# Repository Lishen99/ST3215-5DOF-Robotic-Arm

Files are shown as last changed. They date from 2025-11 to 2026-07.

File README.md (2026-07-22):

# 5-DOF Robotic Arm Control System

Advanced control system for a 5-DOF robotic arm using ST3215 servo motors. This repository contains **multiple control implementations** ranging from direct Python control to high-performance embedded systems, providing flexibility for different applications and performance requirements.

##  Overview

This project features **four distinct control approaches**, each with unique strengths:

1. ** Teensy 4.1 QP-MPC** *(Recommended - Production Ready)*
   - 815Hz control loop with Model Predictive Control
   - Sub-millimeter precision with automatic tuning
   - Best for: Research applications, high-precision tasks

2. ** ESP32 MPC Hybrid**
   - 200Hz Jacobian + MPC constraint projection
   - Balanced performance and complexity
   - Best for: Real-time applications, smooth motion

3. ** ESP32 Jacobian IK**
   - Pure Jacobian velocity control with PID
   - Simple and reliable
   - Best for: Basic automation, learning

4. ** Direct Python Control**
   - PC-based control (Jacob IK / Analytical IK)
   - No microcontroller firmware needed
   - Best for: Prototyping, testing, education

##  Complete Project Structure

```
 ST3215-5DOF-Robotic-Arm/
│
├──  microcontroller_arm_control/     # HIGH-PERFORMANCE EMBEDDED
│   ├── firmware_teensy_qp/             # ★ RECOMMENDED: Teensy 4.1 (815Hz QP-MPC)
│   │   ├── src/main.cpp                # Main control loop
│   │   ├── include/
│   │   │   ├── TinyMPC.h               # QP-MPC controller implementation
│   │   │   ├── Kinematics.h            # FK/IK/Jacobian algorithms
│   │   │   ├── JacobianIK.h            # Jacobian velocity control
│   │   │   └── ServoDriver.h           # ST3215 servo communication
│   │   └── platformio.ini
│   │
│   └── pc_software/                    # Python GUI for Teensy
│       ├── arm_gui.py                  # Main control interface
│       ├── mpc_tuner.py                # Automatic MPC optimizer
│       ├── arm_config.json             # Robot configuration
│       └── mpc_params.json             # Tuned MPC parameters
│
├──  esp32_arm_control/                # ESP32 IMPLEMENTATIONS
│   ├── firmware/                       # ESP32 Jacobian IK (PID-based)
│   │   ├── src/main.cpp                # Pure Jacobian control (~200Hz)
│   │   ├── include/
│   │   │   ├── Kinematics.h
│   │   │   ├── ServoDriver.h
│   │   │   ├── PID.h
│   │   │   └── Trajectory.h
│   │   └── platformio.ini
│   │
│   ├── firmware_mpc/                   # ESP32 Hybrid (Jacobian + MPC)
│   │   ├── src/main.cpp                # Jacobian + MPC constraints
│   │   ├── include/
│   │   │   ├── TinyMPC.h
│   │   │   ├── JacobianController.h
│   │   │   ├── AnalyticalIK.h
│   │   │   └── ArmModel.h
│   │   └── platformio.ini
│   │
│   └── pc_software/                    # Python GUI for ESP32
│       ├── arm_gui.py                  # Control interface (compatible with both firmwares)
│       ├── auto_pid_calibrate.py       # PID auto-tuner
│       └── arm_config.json
│
├──  jacob_ik/                         # PYTHON JACOBIAN CONTROL
│   ├── arm_controller.py               # Direct USB control (PC-based)
│   ├── motor_gui.py                    # Real-time GUI with 3D visualization
│   ├── kinematics.py                   # FK/IK/Jacobian/DLS implementation
│   ├── trajectory.py                   # Path planning
│   ├── joint_control.py                # Per-joint controllers
│   ├── calibrate_servos.py             # Servo calibration tool
│   └── servo_limits.json               # Joint limits and parameters
│
├──  analytical_ik/                    # PYTHON ANALYTICAL CONTROL
│   ├── arm_controller.py               # Direct USB control (PC-based)
│   ├── motor_gui.py                    # GUI interface
│   ├── kinematics.py                   # Closed-form IK solution
│   ├── calibrate_servos.py             # Calibration tool
│   └── servo_limits.json
│
├──  Arm_Design/                       # MECHANICAL CAD FILES
│   ├── Assembly.SLDASM                 # SolidWorks assembly
│   ├── *.SLDPRT                        # Individual parts
│   └── STL/                            # 3D printable files
│
├──  waveshare_diagnostic/             # TESTING & DIAGNOSTICS
│   ├── test_motor1.py                  # Individual motor tests
│   ├── scan_baud.py                    # Baud rate scanner
│   └── recover_servos.py               # Servo recovery tools
│
├──  requirements.txt                  # Python dependencies
└──  README.md                         # This file

```

---

##  Implementation #1: Teensy 4.1 QP-MPC (Recommended)

### Overview
**Highest performance** system with Model Predictive Control running at **815Hz**. Uses Quadratic Programming (QP) solver for optimal control with terminal posture constraints.

### Key Features
- **815Hz Control Loop** (IMXRT1062 @ 600MHz)
- **QP-MPC Controller** with 6 tunable weights
- **Terminal Posture Control** (maintains "elbow-up" configuration)
- **Automatic Parameter Tuning** with deep optimization mode
- **Smooth Path Planning** with cubic spline interpolation
- **Circular Buffer** (200 waypoints) for continuous motion
- **Sub-millimeter Precision** (<0.5mm steady-state error)

### Control Modes
- **M (Cartesian)**: XYZ positioning with Jacobian IK + MPC tracking
- **D (Direct Joint)**: Direct joint angle control (radians) with MPC
- **W (Path)**: Multi-waypoint trajectories with smooth blending
- **Sweep**: Continuous axis scanning for workspace exploration

### Setup & Usage

**Flash Firmware:**
```bash
cd microcontroller_arm_control/firmware_teensy_qp
pio run --target upload
```

**Run GUI:**
```bash
cd ../pc_software
python arm_gui.py
```
- Connect to COM port (921600 baud)
- GUI auto-loads `mpc_params.json`
- Use XYZ control, path planning, or sweep modes

**MPC Tuning:**
```bash
python mpc_tuner.py
```
- **Modes**: Quick (5-10min) / Standard (15-25min) / Deep (1-2hr)
- **Goals**: Fast / Precise / Smooth / Ultimate
- Auto-saves to `mpc_params.json`

### Performance Metrics
- Control Rate: **815Hz**
- Position Error: **<0.5mm**
- Settling Time: **<2s**
- Zero Overshoot (with Ultimate tuning)

### Serial Commands
```
M x y z roll time          # Cartesian move
D q1 q2 q3 q4 roll        # Direct joint (radians)
W x y z roll wait         # Add waypoint
WEXEC                     # Execute path
MPCSET Qpos 150.0         # Set MPC weight
MPCGET                    # Read weights
P                         # Get position
S                         # Stop
```

---

##  Implementation #2: ESP32 MPC Hybrid

### Overview
**Balanced approach** combining Jacobian velocity control with MPC constraint projection. Runs at ~200Hz on ESP32.

### Key Features
- **200Hz Control Loop** (ESP32-WROOM @ 240MHz)
- **Jacobian Velocity Control** for smooth Cartesian motion
- **MPC Constraint Projection** for safe operation at joint limits
- **Null-space Posture Control** (elbow-up preference)
- Compatible with ESP32 GUI (`esp32_arm_control/pc_software/arm_gui.py`)

### Architecture
1. Jacobian computes desired joint velocities
2. Null-space projection optimizes posture
3. MPC ensures velocities respect constraints
4. Servo driver executes safe commands

### Setup
```bash
cd esp32_arm_control/firmware_mpc
pio run --target upload

cd ../pc_software
python arm_gui.py
```

### When to Use
- Need smooth Jacobian control + safety constraints
- ESP32 platform required
- 200Hz sufficient for application
- Don't need ultimate precision of Teensy MPC

---

## 🔧 Implementation #3: ESP32 Jacobian IK

### Overview
**Simplest embedded solution** using pure Jacobian velocity control with PID. Reliable and easy to understand.

### Key Features
- **~200Hz Control Loop** on ESP32
- **Pure Jacobian Velocity Control**
- **Per-joint PID Controllers** (tuned for smooth motion)
- **Trajectory Generation** for blended paths
- **Auto-PID Tuner** available (`auto_pid_calibrate.py`)

### Control Architecture
1. Inverse kinematics computes target joint angles
2. PIDs generate velocity commands per joint
3. Trajectory planner blends waypoints
4. No MPC overhead - simple and fast

### Setup
```bash
cd esp32_arm_control/firmware
pio run --target upload

cd ../pc_software
python arm_gui.py
```

### PID Tuning
```bash
cd esp32_arm_control/pc_software
python auto_pid_calibrate.py
```

### When to Use
- Learning embedded control systems
- Don't need MPC complexity
- Want simple, maintainable code
- Basic automation tasks

---

##  Implementation #4: Direct Python Control

### Overview
**PC-based control** without microcontroller firmware. Python directly commands servos via USB. Two variants available:

### A) Jacob IK (Jacobian-based)
**Location**: `jacob_ik/`

**Features:**
- Jacobian velocity control from PC
- Damped Least Squares (DLS) for singularity handling
- Real-time 3D visualization
- Trajectory planning
- Per-joint controllers with PID

**Setup:**
```bash
cd jacob_ik
python calibrate_servos.py  # First time setup
python motor_gui.py
```

**Pros:**
- No firmware needed
- Easy to modify and experiment
- Full Python debugging tools
- Real-time plotting

**Cons:**
- USB latency (~10-50ms)
- Lower control rate (~20-50Hz)
- PC must stay connected

### B) Analytical IK (Closed-form)
**Location**: `analytical_ik/`

**Features:**
- Closed-form inverse kinematics
- No iterative solving
- Fast and deterministic
- Simple architecture

**Setup:**
```bash
cd analytical_ik
python calibrate_servos.py  # First time setup
python motor_gui.py
```

**Pros:**
- Deterministic IK solution
- No Jacobian singularities
- Simple to understand
- Fast computation

**Cons:**
- Limited to specific arm configurations
- Less flexible than Jacobian
- USB latency limitations

### When to Use Python Control
- **Prototyping** new algorithms
- **Testing** hardware before firmware
- **Education** - understanding control theory
- **Research** - need Python ecosystem (numpy, scipy, matplotlib)
- **Quick experiments** without reflashing firmware

---

##  Hardware Specifications

### Required Components
- **Microcontroller** (choose one):
  - **Teensy 4.1** (recommended) - 600MHz, 815Hz control
  - **ESP32-WROOM** - 240MHz, 200Hz control
  - **PC with Python** - Direct USB control
  
- **Servos**: 5x ST3215 (or 6 with wrist roll)
- **Power Supply**: 12V for servos
- **USB Cable**: Micro-USB or USB-C depending on board

### Robot Arm Specifications
- **DOF**: 5 (Base, Shoulder, Elbow, Wrist Pitch, Wrist Roll)
- **Link Lengths**:
  - L1 (Shoulder-Elbow): 133.39mm
  - L2 (Elbow-Wrist): 124.97mm
  - L3 (Wrist-Tip): 73.39mm
- **Workspace**: ~300mm radius hemisphere
- **Payload**: TBD (depends on servo torque)

### Servo Configuration & Communication

**Servos:**
- **Model**: Waveshare ST3215 Serial Bus Servos
- **Resolution**: 4096 steps/revolution (0.088°/step)
- **Communication Protocol**: Half-duplex serial (RS-485 style)
- **Baud Rate**: 1000000 bps
- **Daisy Chain**: All servos on single serial bus with unique IDs

**Serial Bus Driver Board:**
- **Required**: Waveshare Serial Bus Servo Driver Board or equivalent
- **Function**: Converts TTL serial to half-duplex servo bus
- **Direction Control**: GPIO pin switches between TX/RX
- **Connections**:
  - Microcontroller TX → Driver TX
  - Microcontroller RX → Driver RX
  - Microcontroller GPIO → Driver DIR (direction control)
  - Driver Bus → Servo chain (daisy-chained)

**STServo SDK:**
- **Protocol**: Proprietary Waveshare protocol (similar to Dynamixel)
- **Python SDK**: Included in `STServo_Python/` directory
- **C++ Drivers**: Custom implementations in firmware (`ServoDriver.h`)
- **Commands**: Position, speed, voltage, temperature, torque enable/disable

**Why Serial Bus?**
- Single communication line for all servos (not PWM)
- Position feedback built-in (closed-loop control)
- Daisy-chain reduces wiring complexity
- Real-time telemetry (position, voltage, temperature)

---

##  Installation & Setup Guide

### 1. Clone Repository
```bash
git clone https://github.com/Lishen99/ST3215-5DOF-Robotic-Arm.git
cd ST3215-5DOF-Robotic-Arm/STServo_Python
```

### 2. Python Environment
```bash
python -m venv stservo-env

# Windows
.\stservo-env\Scripts\activate

# macOS/Linux
source stservo-env/bin/activate

pip install -r requirements.txt
pip install scipy  # For smooth path interpolation (Teensy)
```

### 3A. Teensy 4.1 Setup (Recommended)
```bash
# Install PlatformIO
pip install platformio

# Flash firmware
cd microcontroller_arm_control/firmware_teensy_qp
pio run --target upload

# Run GUI
cd ../pc_software
python arm_gui.py
# Select COM port, 921600 baud, Connect

# Optional: Run MPC tuner
python mpc_tuner.py
```

### 3B. ESP32 Setup
```bash
# Choose firmware variant
cd esp32_arm_control/firmware          # Pure Jacobian
# OR
cd esp32_arm_control/firmware_mpc      # Hybrid MPC

pio run --target upload

cd ../pc_software
python arm_gui.py
```

### 3C. Python Direct Control
```bash
# Choose implementation
cd jacob_ik          # Jacobian-based
# OR
cd analytical_ik     # Analytical IK

python calibrate_servos.py    # First time: calibrate centers
python motor_gui.py           # Run controller
```

---

##  Performance Comparison

| Feature | Teensy QP-MPC | ESP32 Hybrid | ESP32 Jacobian | Python Direct |
|---|---|---|---|---|
| **Control Rate** | 815Hz | 200Hz | 200Hz | 20-50Hz |
| **Position Error** | <0.5mm | ~1-2mm | ~2-3mm | ~5-10mm |
| **Settling Time** | <2s | ~3s | ~3-5s | ~5-10s |
| **Smoothness** | Excellent | Very Good | Good | Fair |
| **Tuning Complexity** | High (auto) | Medium | Low (PID) | Low |
| **Code Complexity** | High | Medium | Low | Very Low |
| **Setup Difficulty** | Medium | Medium | Easy | Very Easy |
| **Best For** | Research, Precision | Real-time Apps | Learning | Prototyping |

---

##  Usage Examples

### Example 1: Cartesian Move (Teensy)
```bash
# Connect GUI → arm_gui.py
# Enter coordinates: X=200, Y=100, Z=150
# Click "Move To"
```

**Serial Command:**
```
M 200 100 150 0 2.0    # Move to (200,100,150) in 2s
```

### Example 2: Path Execution with Loop
```bash
# Add waypoints in GUI
# Select "Smooth" mode
# Enable "Loop"
# Click "Execute Path"
```

### Example 3: MPC Tuning
```bash
cd microcontroller_arm_control/pc_software
python mpc_tuner.py

# Select "Deep" mode
# Choose "Ultimate" goal
# Click "Start Tuning"
# Wait 1-2 hours
# Results auto-saved to mpc_params.json
```

### Example 4: Python Jacobian Control
```bash
cd jacob_ik
python motor_gui.py

# Connect to COM port
# Scan motors
# Use "Cartesian Control" panel
# Enter X, Y, Z coordinates
# Click "Move"
```

---

##  Key Algorithms

### QP-MPC (Teensy Implementation)

**Cost Function:**
```
J = ||q - q_ref||²_Qpos + ||q̇ - q̇_ref||²_Qvel + 
    ||q_final - q_target||²_Qfpos + ||q̇_final||²_Qfvel +
    ||u||²_R + ||Δu||²_Rdelta
```

**Parameters (Ultimate Tuning):**
- `Qpos`: Position tracking weight
- `Qvel`: Velocity tracking weight
- `Qfpos`: Terminal position (posture control)
- `Qfvel`: Terminal velocity (smooth stop)
- `R`: Control effort penalty
- `Rdelta`: Jerk penalty (smoothness)

**Terminal Posture Control:**
- Optimizes final joint configuration
- Maintains "elbow-up" for better workspace reach
- Prevents awkward singularity-prone poses

### Jacobian Velocity Control (All Implementations)

**Damped Least Squares (DLS):**
```python
J_inv = J.T @ inv(J @ J.T + λ²I)
q̇ = J_inv @ ẋ_desired
```

**Adaptive Damping:**
```python
λ = λ_base * (1 + exp(-k * manipulability))
```

**Null-space Projection:**
```python
N = I - J_inv @ J
q̇_posture = N @ (q_neutral - q_current)
q̇_final = q̇_task + α * q̇_posture
```

---

##  Troubleshooting

### Teensy Not Connecting
- Check COM port in Device Manager
- Verify 921600 baud rate
- Press Teensy button to enter bootloader
- Reflash firmware: `pio run --target upload`

### Motors Not Responding
```bash
cd waveshare_diagnostic
python scan_baud.py        # Find correct baud rate
python test_motor1.py      # Test individual motor
python recover_servos.py   # Factory reset if needed
```

### Poor Motion Quality
1. **Teensy**: Run MPC tuner (`mpc_tuner.py`)
2. **ESP32 Jacobian**: Run PID tuner (`auto_pid_calibrate.py`)
3. **Python**: Adjust damping in `kinematics.py`

### Arm Shaking/Oscillating
- **Teensy**: Increase `Rdelta` (jerk penalty) via `MPCSET Rdelta 0.5`
- **ESP32**: Lower PID D-gains
- **All**: Reduce speed multiplier

### Path Not Smooth
- Enable "Smooth" mode in path planning
- Increase blend radius
- Use more intermediate waypoints
- Check J1 wrapping logic for base rotation

---

##  Key Innovations

### 1. Terminal Posture MPC
MPC optimizes not just trajectory tracking but also **terminal joint configuration**. This maintains favorable "elbow-up" poses and avoids singularities automatically.

### 2. Intelligent J1 Wrapping
When base rotation exceeds ±180°, system automatically inserts intermediate waypoints to prevent infinite spinning through cable wraps.

### 3. Circular Buffer Management
200-waypoint circular buffer with intelligent top-up ensures smooth motion during long paths without USB latency affecting real-time control.

### 4. Velocity-Based Tuning
MPC tuner penalizes slow movements (<17°/s) that cause backlash jitter, ensuring confident motion while still allowing settling.

### 5. High-Resolution Error Tracking
Uses raw servo positions (4096 steps/rev) instead of floating-point angles for tuning - achieves higher precision in optimization.

---

## 📚 Additional Resources

### Calibration Tools (`waveshare_diagnostic/`)
- `test_motor1.py` - Test individual motor
- `scan_baud.py` - Auto-detect baud rate
- `full_scan.py` - Scan all motor IDs
- `recover_servos.py` - Factory reset servos

### Mechanical Design (`Arm_Design/`)
- SolidWorks assembly and parts
- STL files for 3D printing
- Bearing specifications
- Bill of materials in assembly

### Configuration Files
- `servo_limits.json` - Joint limits, centers, PID gains
- `arm_config.json` - Link lengths, workspace bounds
- `mpc_params.json` - Optimized MPC weights

---

##  Known Issues & Future Work

### Current Limitations
1. **Motor 6 (Roll)**: Excluded from MPC tuning for safety
2. **Z-Limit**: Currently -150mm, could extend with better singularity handling
3. **Python Control**: USB latency limits performance

### Planned Improvements
- [ ] Adaptive MPC weights based on workspace region
- [ ] Vision-based feedback control
- [ ] Force/torque sensing
- [ ] Multi-arm coordination
- [ ] ROS integration
- [ ] Machine learning for parameter optimization

---

##  License

This project is licensed under the [Creative Commons Attribution-NonCommercial-ShareAlike 4.0 International (CC BY-NC-SA 4.0) License](https://creativecommons.org/licenses/by-nc-sa/4.0/).

You are free to share and adapt the material for non-commercial purposes, provided appropriate credit is given and any adaptations are shared under the same license.

---

##  Credits

- **Hardware/SDK**: Waveshare ST3215 servo motors and STServo SDK
- **MPC Library**: Custom QP-MPC implementation based on TinyMPC concepts
- **Development**: Lishen99
- **Control Theory**: Classical Jacobian IK, MPC optimization, DLS

---

##  Contact & Support

- **GitHub Issues**: [Report bugs or request features](https://github.com/Lishen99/ST3215-5DOF-Robotic-Arm/issues)
- **Discussions**: Share your builds and ask questions
- **Pull Requests**: Contributions welcome!

---

** Choose Your Implementation:**
-  **Research/Precision** → Teensy QP-MPC (815Hz)
-  **Real-time Apps** → ESP32 MPC Hybrid (200Hz)
-  **Learning/Automation** → ESP32 Jacobian IK
-  **Prototyping/Testing** → Python Direct Control

**Happy Building! **

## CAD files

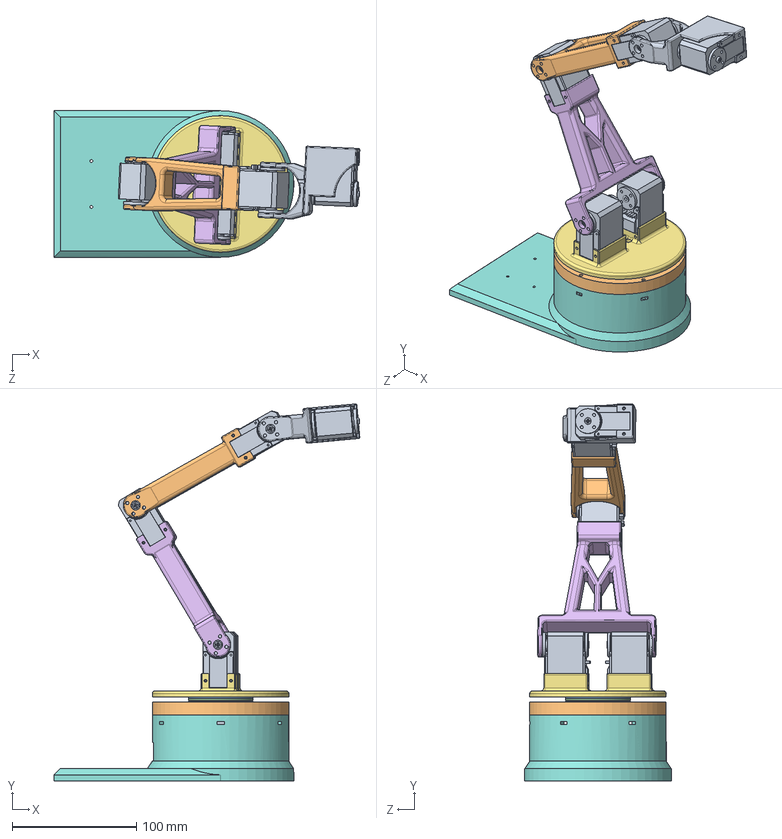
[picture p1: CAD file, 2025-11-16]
Arm Design/Assembly.SLDASM
246.1 x 303.6 x 118.0 mm
StaticBaseServoPlate
STS3215 x 6
StaticBase
BaseRotatingPlate
ShoulderLinkCentered
5972K216_Ball Bearing
5909K18_Needle-Roller Thrust Bearing
5909K78_1 mm Thick Washer for 35 mm Shaft Diameter Needle-Roller Thrust Bearing x 2
ElbowLinkCentered
WristLink

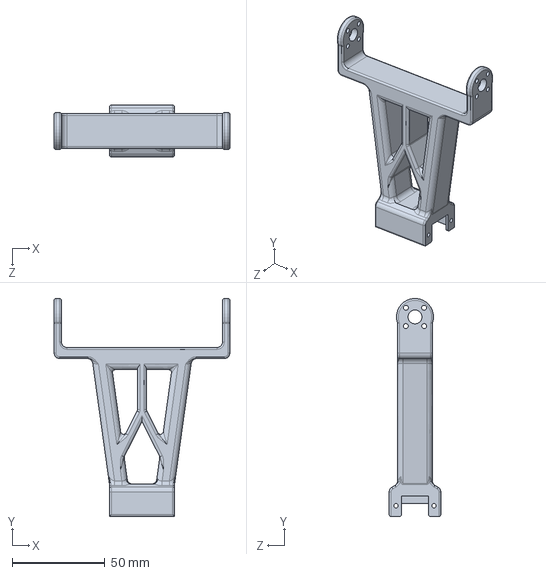
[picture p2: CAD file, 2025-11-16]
Arm Design/ShoulderLinkCentered.SLDPRT
94.9 x 117.7 x 27.9 mm

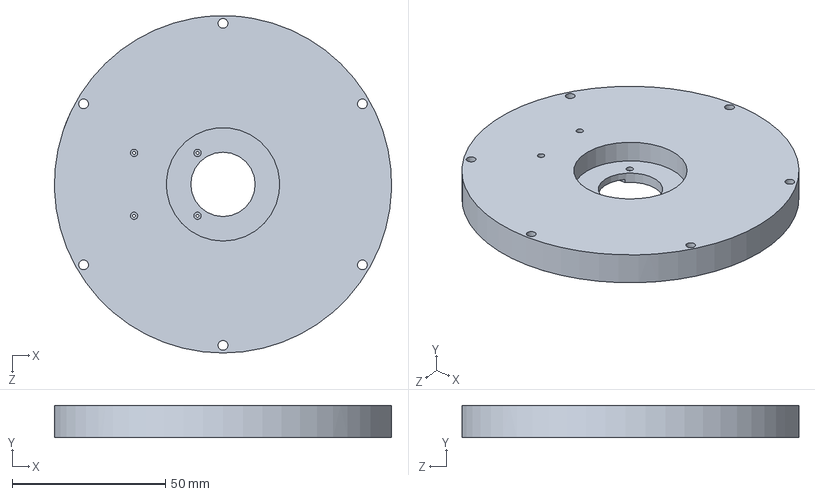
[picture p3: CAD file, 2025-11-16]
Arm Design/StaticBaseServoPlate.SLDPRT
110.0 x 10.5 x 109.9 mm

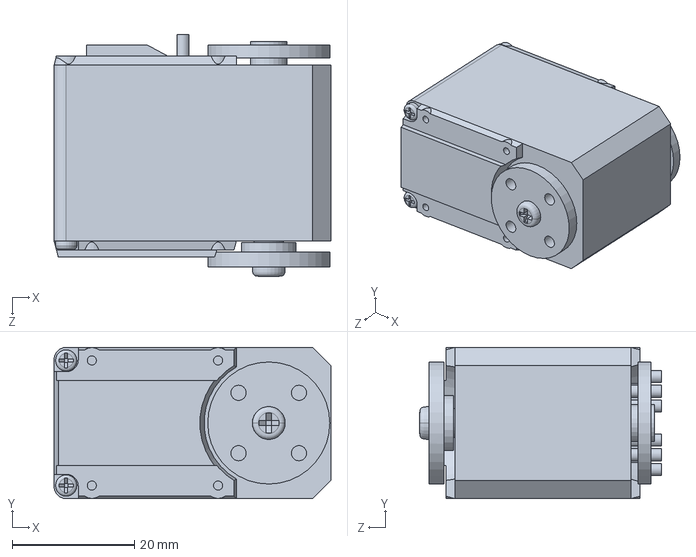
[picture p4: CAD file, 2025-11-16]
Arm Design/STS3215.SLDPRT
45.4 x 24.8 x 39.6 mm

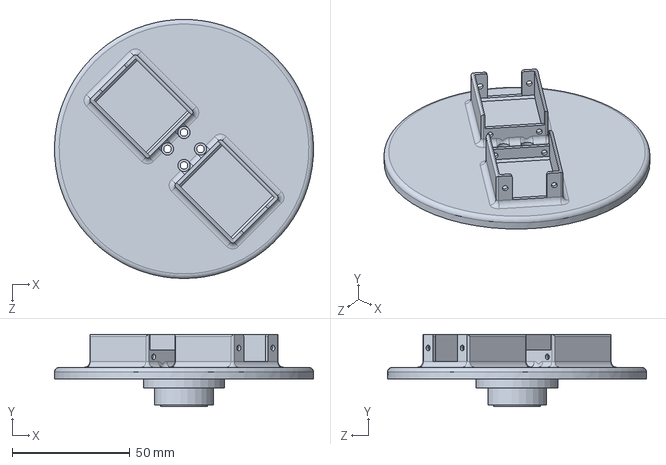
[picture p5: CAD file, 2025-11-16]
Arm Design/BaseRotatingPlate.SLDPRT
110.0 x 30.7 x 110.0 mm

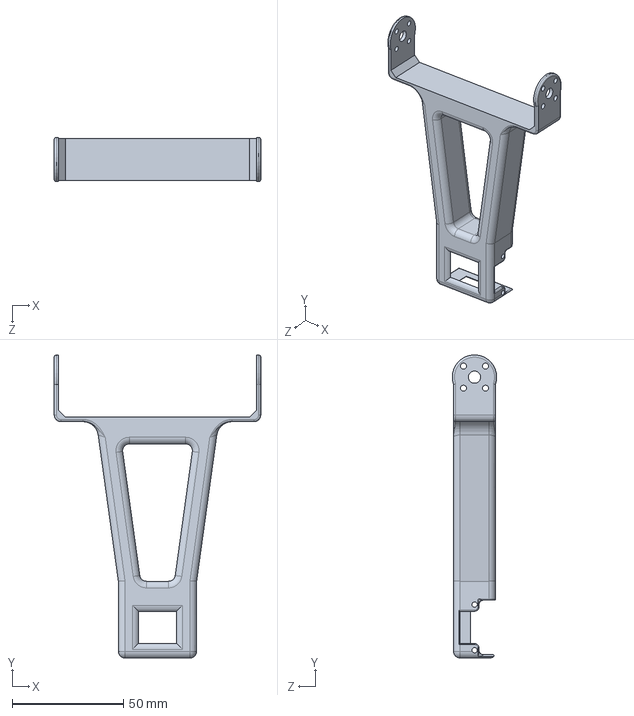
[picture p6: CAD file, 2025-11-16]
Arm Design/ShoulderLink.SLDPRT
92.9 x 136.2 x 20.0 mm

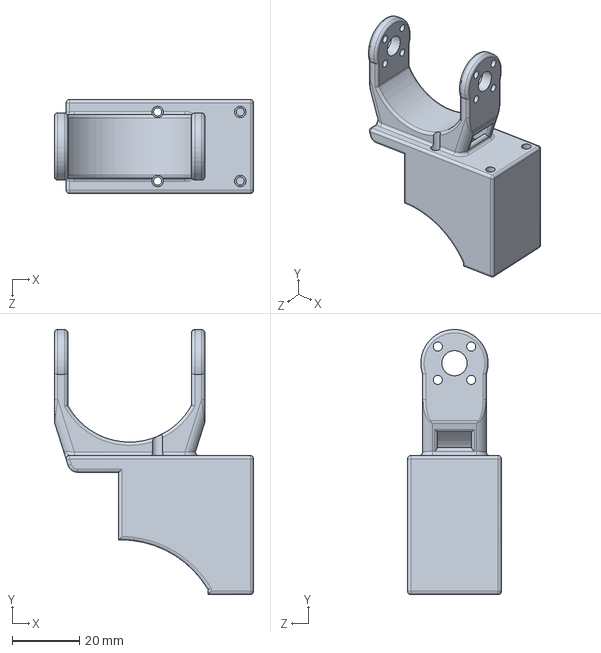
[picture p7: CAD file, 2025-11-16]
Arm Design/WristLink.SLDPRT
59.1 x 78.6 x 27.9 mm

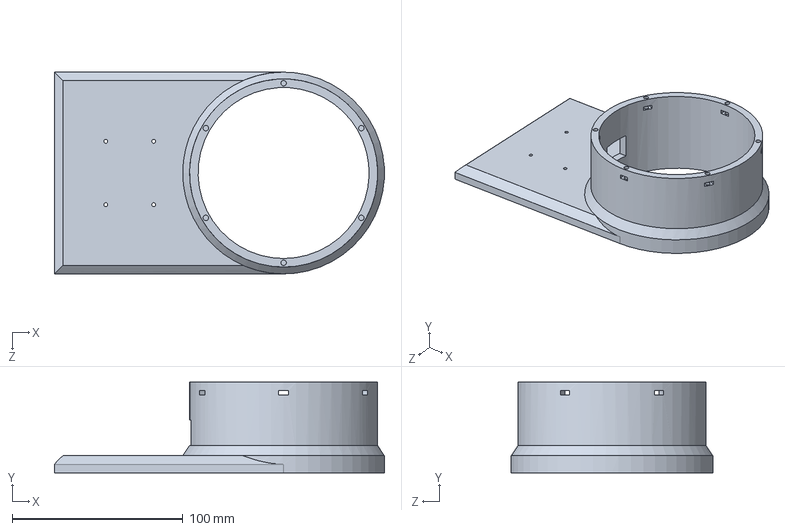
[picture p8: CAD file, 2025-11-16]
Arm Design/StaticBase.SLDPRT
193.0 x 53.0 x 118.0 mm

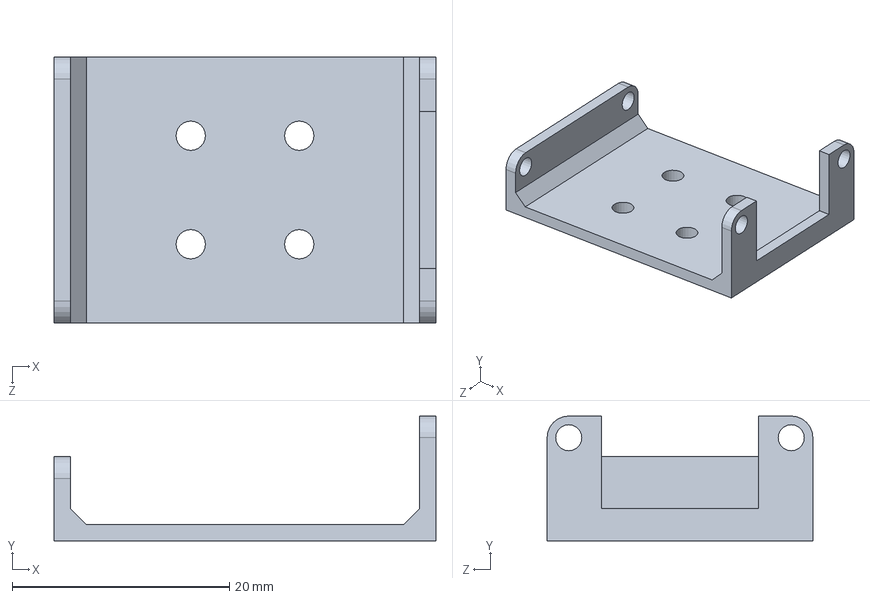
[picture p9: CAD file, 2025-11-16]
Arm Design/BottomV2.SLDPRT
35.2 x 11.5 x 24.5 mm

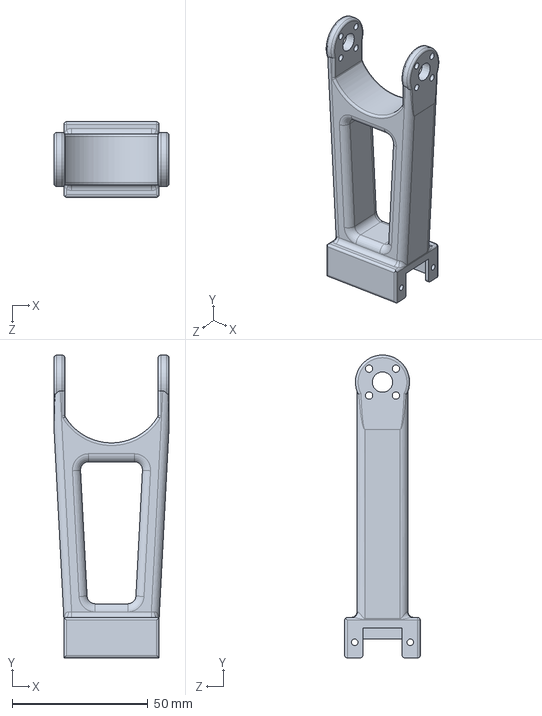
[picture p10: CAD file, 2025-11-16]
Arm Design/ElbowLinkCentered.SLDPRT
42.4 x 111.8 x 27.9 mm

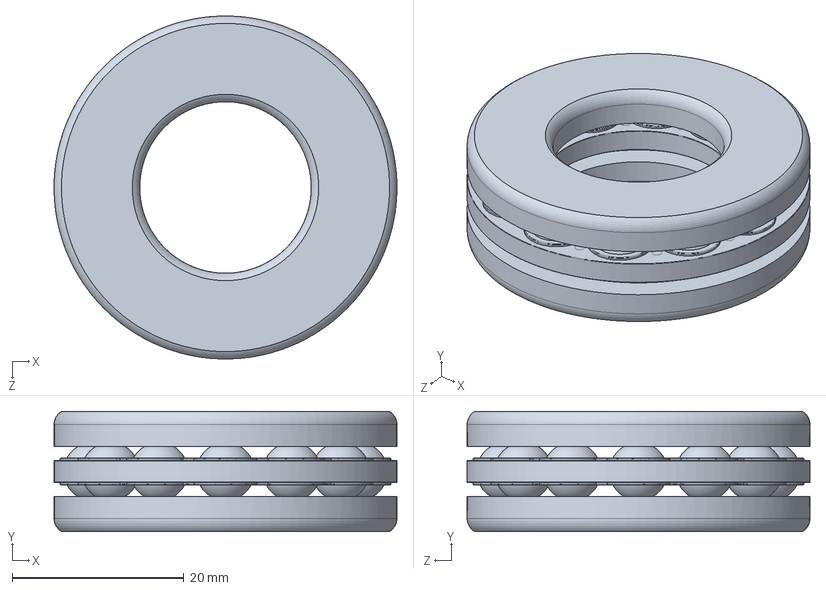
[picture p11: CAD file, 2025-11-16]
Arm Design/7806K755_Thrust Ball Bearing.SLDPRT
40.0 x 14.0 x 40.0 mm

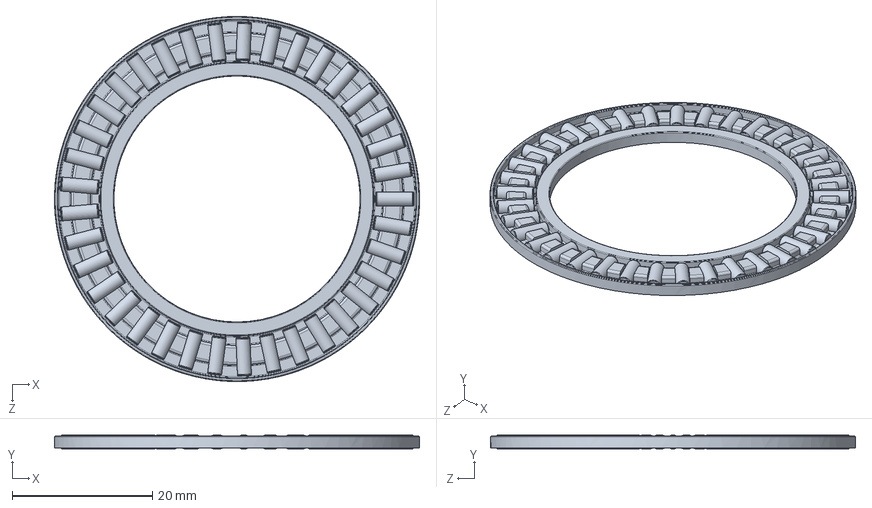
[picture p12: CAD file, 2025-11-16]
Arm Design/5909K18_Needle-Roller Thrust Bearing.SLDPRT
52.0 x 2.00 x 52.0 mm

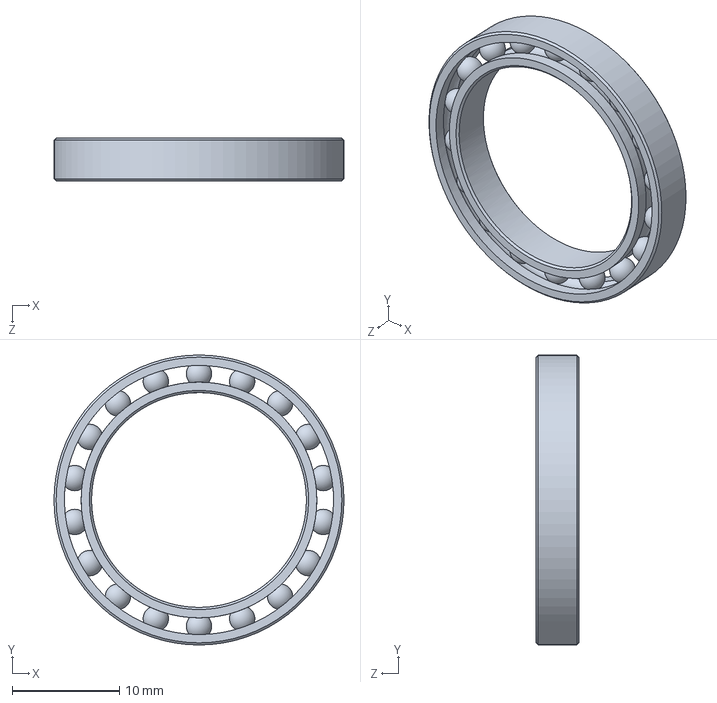
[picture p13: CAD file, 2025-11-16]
Arm Design/6656K101_Ultra-Thin Ball Bearing.SLDPRT
27.0 x 27.0 x 4.00 mm

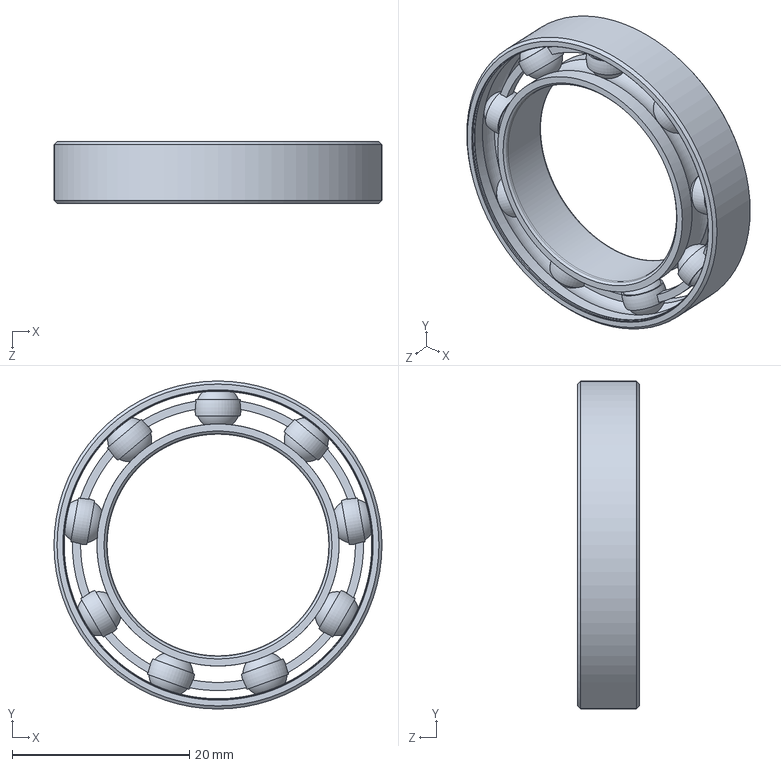
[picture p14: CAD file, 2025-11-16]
Arm Design/5972K216_Ball Bearing.SLDPRT
37.0 x 37.0 x 7.00 mm

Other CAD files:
Arm Design/5909K78_1 mm Thick Washer for 35 mm Shaft Diameter Needle-Roller Thrust Bearing.SLDPRT
Arm Design/STL/BaseRotatingPlate.STL
Arm Design/STL/ElbowLinkCentered.STL
Arm Design/STL/ShoulderLinkCentered.STL
Arm Design/STL/StaticBase.STL
Arm Design/STL/StaticBaseServoPlate.STL
Arm Design/STL/WristLink.STL

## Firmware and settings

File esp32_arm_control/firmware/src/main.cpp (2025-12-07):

#include <Arduino.h>
#include "Kinematics.h"
#include "ServoDriver.h"
#include "PID.h"
#include "Trajectory.h"

// Pin Definitions for ESP32-WROOM-32E
#define SERVO_RX_PIN 16 // RX2
#define SERVO_TX_PIN 17 // TX2
#define SERVO_DIR_PIN 4 // GPIO for RS-485 direction control

// Objects
ServoDriver servoDriver(Serial2, SERVO_DIR_PIN, SERVO_RX_PIN, SERVO_TX_PIN);
Kinematics kinematics;
Trajectory trajectory;

// PIDs - 4 joints for IK (Base, Shoulder, Elbow, WristPitch) + WristRoll separate
// Tuned for smooth motion with less overshoot
PID pids[5] = {
    PID(8.0, 0.0, 0.8, 1500),   // Base (motor 1) - lower P, higher D
    PID(12.0, 0.0, 1.0, 1500),  // Shoulder (motor 2) - lower P, higher D
    PID(12.0, 0.0, 1.0, 1500),  // Elbow (motor 4)
    PID(10.0, 0.0, 0.6, 1500),  // Wrist Pitch (motor 5)
    PID(8.0, 0.0, 0.4, 1500)    // Wrist Roll (motor 6)
};

// State - using volatile for cross-task access
volatile bool moving = false;
volatile bool joint_mode = false; // False = Cartesian (IK), True = Joint Space
volatile bool torque_enabled = true;
volatile bool position_valid = false;

// Protected shared data with mutex
SemaphoreHandle_t stateMutex;
SemaphoreHandle_t pidMutex; // Separate mutex for PID access
Matrix<4> current_q = {0, 0, 0, 0};     // 4-DOF for IK
Matrix<3> current_pos = {0, 0, 0};      // XYZ end-effector
float current_roll = 0;                  // Wrist roll stored separately

// Motor IDs - 6 motors: 1=Base, 2&3=Shoulder(coupled), 4=Elbow, 5=WristPitch, 6=WristRoll
std::vector<uint8_t> motor_ids = {1, 2, 3, 4, 5, 6}; 

// Motor Centers calculated from servo_limits.json: (min + max) / 2
// Motor 1: Manually calibrated to 2207
// Motor 2: (1365+3869)/2=2617, Motor 3: (1521+4021)/2=2771
// Motor 4: (1324+3803)/2=2563, Motor 5: (854+3466)/2=2160
// Motor 6: (0+4095)/2=2047
int centers[6] = {2207, 2617, 2771, 2563, 2160, 2047}; 

// Last known good positions for fallback
int lastPositions[6] = {2207, 2617, 2771, 2563, 2160, 2047};

// Raw positions for telemetry
int rawPositions[6] = {2207, 2617, 2771, 2563, 2160, 2047};

// Consecutive read failure counter
int readFailCount = 0;
const int MAX_READ_FAILS = 10;

// Target wrist angle for IK (pitch angle of end effector from horizontal)
float target_wrist_angle = 0.0f; // radians

// Move command parameters (set by loop(), read by controlTask())
float move_target_x = 0, move_target_y = 0, move_target_z = 0;
float move_target_roll = 0, move_duration_global = 1.0f;
Matrix<4> move_start_q = {0, 0, 0, 0};
Matrix<4> move_end_q = {0, 0, 0, 0};
float move_start_roll = 0, move_end_roll = 0;

// Direct joint target mode (for slider control)
volatile bool direct_joint_mode = false;
Matrix<4> direct_joint_target = {0, 0, 0, 0};
float direct_roll_target = 0;

// Sweep mode for continuous trajectory
volatile bool sweep_mode = false;
int sweep_axis = 0;  // 0=X, 1=Y, 2=Z
float sweep_velocity = 50.0f;  // mm/s
int sweep_direction = 1;  // 1 or -1
Matrix<3> sweep_start_pos = {200, 0, 200};  // Store initial position when sweep starts
bool sweep_initialized = false;

// Speed multiplier (adjustable from GUI, 0.5 to 2.0)
float speed_multiplier = 2.0f;  // Default 2x speed

// Wrist mode: true = locked at target_wrist_angle, false = free (IK controls it)
bool wrist_locked = true;

// Cartesian target for Jacobian-based control
Matrix<3> cartesian_target = {200, 0, 200};
volatile bool cartesian_mode = false;

// Center-crossing state: when moving from +X to -X (or vice versa), go to neutral first
volatile bool center_crossing_mode = false;

// FLIP MODE: Joint-space interpolation for large base rotations
// When target needs >90° base rotation, we flip arm configuration instead
volatile bool flip_mode = false;                  // Currently in flip interpolation?
Matrix<4> flip_start_q = {0, 0, 0, 0};           // Joint state when flip started
Matrix<4> flip_target_q = {0, 0, 0, 0};          // Target joint state after flip
float flip_start_roll = 0.0f;
float flip_target_roll = 0.0f;
volatile unsigned long flip_start_time = 0;
volatile float flip_duration = 1.0f;                       // Seconds for flip interpolation
Matrix<3> flip_final_cartesian = {0, 0, 0};      // Final Cartesian target after flip
float flip_final_roll = 0.0f;
Matrix<3> final_target_after_neutral = {0, 0, 0};
float final_roll_after_neutral = 0.0f;

// ========== SMOOTH PATH FOLLOWING ==========
// Waypoint queue for continuous motion without stops
struct Waypoint {
    float x, y, z, roll;
    float wait_time;  // 0 = blend through, >0 = stop and wait
};
const int MAX_WAYPOINTS = 32;
Waypoint path_waypoints[MAX_WAYPOINTS];
int path_count = 0;           // Total waypoints in path
int path_current_idx = 0;     // Current waypoint index
volatile bool path_mode = false;
float path_blend_radius = 15.0f;  // Start blending to next waypoint when within this distance (mm)
unsigned long path_wait_start = 0;
bool path_waiting = false;

// Backlash compensation: ~0.6 degrees = 0.0105 radians per joint
const float BACKLASH_RAD = 0.0105f;  // 0.6 degrees in radians
// Track previous direction for each joint (1 = positive, -1 = negative, 0 = stopped)
int prev_direction[6] = {0, 0, 0, 0, 0, 0};
// Accumulated backlash compensation for each motor
float backlash_offset[6] = {0.0f, 0.0f, 0.0f, 0.0f, 0.0f, 0.0f};

// Helper to map raw (0-4095) to radians based on center
float rawToRad(int raw, int center_raw) {
    return (raw - center_raw) * (2.0f * PI / 4096.0f);
}

// Helper to map radians to raw
int radToRaw(float rad, int center_raw) {
    return center_raw + (int)(rad * 4096.0f / (2.0f * PI));
}

// CRITICAL: Motor 1 (base) cannot wrap around 0↔4095
// Safe range is 100 to 3995 (with small margin from 0 and 4095)
// Center is 2207, so safe range in radians is about ±2.75 rad (±158°)
const int BASE_MIN_RAW = 100;
const int BASE_MAX_RAW = 3995;
const float BASE_MIN_RAD = (BASE_MIN_RAW - 2207) * (2.0f * PI / 4096.0f);  // ~-3.23 rad
const float BASE_MAX_RAD = (BASE_MAX_RAW - 2207) * (2.0f * PI / 4096.0f);  // ~+2.75 rad

// Clamp base angle to valid range (prevents wrapping)
float clampBaseAngle(float q1_rad) {
    if (q1_rad > BASE_MAX_RAD) return BASE_MAX_RAD;
    if (q1_rad < BASE_MIN_RAD) return BASE_MIN_RAD;
    return q1_rad;
}

// Clamp base velocity to prevent crossing the no-go zone
// Returns clamped velocity (0 if would cross limit)
float clampBaseVelocity(float q1_current_rad, float q1_dot, int raw_pos) {
    // If moving toward a limit, check if we're close
    const float MARGIN_RAD = 0.1f;  // ~6 degrees safety margin
    
    if (q1_dot > 0 && (q1_current_rad > BASE_MAX_RAD - MARGIN_RAD || raw_pos > BASE_MAX_RAW - 50)) {
        // Moving positive but near max limit - stop
        return 0.0f;
    }
    if (q1_dot < 0 && (q1_current_rad < BASE_MIN_RAD + MARGIN_RAD || raw_pos < BASE_MIN_RAW + 50)) {
        // Moving negative but near min limit - stop
        return 0.0f;
    }
    return q1_dot;
}

// Clamp base motor speed based on current position
int clampBaseSpeed(float q1_current_rad, int speed, int raw_pos) {
    const float MARGIN_RAD = 0.1f;
    
    if (speed > 0 && (q1_current_rad > BASE_MAX_RAD - MARGIN_RAD || raw_pos > BASE_MAX_RAW - 50)) {
        return 0;
    }
    if (speed < 0 && (q1_current_rad < BASE_MIN_RAD + MARGIN_RAD || raw_pos < BASE_MIN_RAW + 50)) {
        return 0;
    }
    return speed;
}

// Clamp joint angles to within limits
Matrix<4> clampJointsToLimits(const Matrix<4>& q) {
    Matrix<4> result = q;
    for (int i = 0; i < 4; i++) {
        if (result(i) < JOINT_LIMITS[i].min_rad) result(i) = JOINT_LIMITS[i].min_rad;
        if (result(i) > JOINT_LIMITS[i].max_rad) result(i) = JOINT_LIMITS[i].max_rad;
    }
    return result;
}

// Check if target joint configuration is valid (within limits)
bool isJointConfigValid(const Matrix<4>& q) {
    for (int i = 0; i < 4; i++) {
        if (q(i) < JOINT_LIMITS[i].min_rad || q(i) > JOINT_LIMITS[i].max_rad) {
            return false;
        }
    }
    return true;
}

// Calculate "flipped" joint configuration (for crossing +X to -X)
// 
// From the logs, when arm reaches -X with elbow-up:
//   J2 ≈ +1.7 (shoulder tilted BACK - positive!)
//   J3 ≈ -1.75 (elbow bent)
//   J4 ≈ +2.0 (wrist compensating)
//
// When arm reaches +X with elbow-up:
//   J2 ≈ -0.1 (shoulder slightly forward - negative)
//   J3 ≈ -1.6 (elbow bent)
//   J4 ≈ -0.5 (wrist compensating)
//
// So the flip is essentially: swap J2 sign (and magnitude), adjust J4
Matrix<4> computeFlippedConfig(const Matrix<4>& current_q, const Matrix<3>& target_xyz) {
    Matrix<4> flipped = current_q;
    
    // Determine direction of flip based on target X
    bool going_to_negative_x = target_xyz(0) < 0;
    
    if (going_to_negative_x) {
        // Going to -X: need J2 positive (shoulder tilted back)
        // This puts the elbow high and behind, forearm reaches down toward -X
        flipped(1) = 1.5f;  // Shoulder back - POSITIVE
        
        // J3 stays negative (elbow bent)
        flipped(2) = fmin(current_q(2), -1.5f);  // Keep good bend
        
        // J4 needs to keep gripper roughly level pointing toward -X
        // When J2=1.5, J3=-1.5, we need J4 to compensate
        // For horizontal gripper: J2 + J3 + J4 ≈ 0 (but accounting for offsets)
        flipped(3) = 1.8f;  // Wrist pitched up significantly
        
    } else {
        // Going to +X: need J2 slightly negative (shoulder forward)
        flipped(1) = -0.1f;
        
        // J3 negative (elbow bent)
        flipped(2) = fmin(current_q(2), -1.2f);
        
        // J4 for forward-pointing gripper
        float j2_angle = flipped(1) + M_PI_2;
        float target_phi = 0.0f;  // Point forward
        flipped(3) = target_phi - j2_angle - flipped(2);
    }
    
    // Clamp to joint limits
    flipped = clampJointsToLimits(flipped);
    
    return flipped;
}

// Apply backlash compensation to motor speeds
// When direction reverses, add extra steps to overcome backlash
void applyBacklashCompensation(std::vector<int>& speeds) {
    const int BACKLASH_STEPS = 7;  // ~0.6 degrees = 6.8 steps, round to 7
    const int SPEED_THRESHOLD = 10;  // Minimum speed to consider "moving"
    
    for (size_t i = 0; i < speeds.size() && i < 6; i++) {
        int new_direction = 0;
        if (speeds[i] > SPEED_THRESHOLD) new_direction = 1;
        else if (speeds[i] < -SPEED_THRESHOLD) new_direction = -1;
        
        // Check for direction reversal
        if (new_direction != 0 && prev_direction[i] != 0 && new_direction != prev_direction[i]) {
            // Direction reversed - add compensation in the new direction
            backlash_offset[i] = BACKLASH_STEPS * new_direction;
        }
        
        // Apply any accumulated compensation
        if (backlash_offset[i] != 0.0f && new_direction != 0) {
            // Add compensation to speed (will be applied over several cycles)
            float comp_speed = backlash_offset[i] * 50.0f;  // Fast compensation
            speeds[i] += (int)comp_speed;
            
            // Decay the compensation
            float decay = fabs(speeds[i]) * 0.001f;  // Decay based on speed
            if (decay < 0.5f) decay = 0.5f;
            if (backlash_offset[i] > 0) {
                backlash_offset[i] -= decay;
                if (backlash_offset[i] < 0) backlash_offset[i] = 0;
            } else {
                backlash_offset[i] += decay;
                if (backlash_offset[i] > 0) backlash_offset[i] = 0;
            }
        }
        
        // Update direction tracking
        if (new_direction != 0) {
            prev_direction[i] = new_direction;
        }
    }
}

// MINIMUM MOTOR SPEED - motors are jerky below this threshold
// Used to boost low speeds to a usable level
const int MIN_MOTOR_SPEED = 50;  // steps/s minimum
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
void loop() {
    if (Serial.available()) {
        String cmd = Serial.readStringUntil('\n');
        cmd.trim();
        
        if (cmd.length() == 0) return;
        
        if (cmd.startsWith("M")) { // Cartesian Move: M x y z roll time
            float x, y, z, roll, t;
            if (sscanf(cmd.c_str(), "M %f %f %f %f %f", &x, &y, &z, &roll, &t) == 5) {
                if (xSemaphoreTake(stateMutex, pdMS_TO_TICKS(100)) == pdTRUE) {
                    // Check if we need to do a flip-over move
                    Matrix<3> current_fk = kinematics.forward_kinematics(current_q);
                    
                    // Calculate base angles for current and target positions
                    float current_base_angle = atan2(current_fk(1), current_fk(0));
                    float target_base_angle = atan2(y, x);
                    
                    // Calculate the angular difference (accounting for wraparound)
                    float angle_diff = target_base_angle - current_base_angle;
                    while (angle_diff > M_PI) angle_diff -= 2.0f * M_PI;
                    while (angle_diff < -M_PI) angle_diff += 2.0f * M_PI;
                    
                    // Check if this requires a flip (>90° base rotation with Y near zero on both ends)
                    bool y_near_zero = fabs(y) < 60.0f && fabs(current_fk(1)) < 60.0f;
                    bool large_rotation = fabs(angle_diff) > M_PI_2 * 0.9f;  // >81° rotation
                    
                    Serial.printf("DBG: FK=(%.1f,%.1f,%.1f) TGT=(%.1f,%.1f,%.1f)\n", 
                        current_fk(0), current_fk(1), current_fk(2), x, y, z);
                    Serial.printf("DBG: base_angles cur=%.2f tgt=%.2f diff=%.2f\n", 
                        current_base_angle, target_base_angle, angle_diff);
                    Serial.printf("DBG: y_near_zero=%d large_rotation=%d\n", y_near_zero, large_rotation);
                    
                    if (y_near_zero && large_rotation) {
                        // FLIP MODE: Instead of rotating base, flip the arm configuration
                        // This gives a smooth, natural motion for +X to -X transitions
                        
                        // Compute the flipped joint configuration
                        Matrix<4> flipped = computeFlippedConfig(current_q, {x, y, z});
                        
                        Serial.printf("DBG: current_q=(%.2f,%.2f,%.2f,%.2f)\n",
                            current_q(0), current_q(1), current_q(2), current_q(3));
                        Serial.printf("DBG: flipped=(%.2f,%.2f,%.2f,%.2f) valid=%d\n",
                            flipped(0), flipped(1), flipped(2), flipped(3), isJointConfigValid(flipped));
                        
                        // Check if flipped config is valid
                        if (isJointConfigValid(flipped)) {
                            // Set up flip interpolation
                            flip_start_q = current_q;
                            flip_target_q = flipped;
                            flip_start_roll = current_roll;
                            flip_target_roll = roll;
                            flip_start_time = 0;  // Sentinel - control task will set actual time
                            
                            // Duration based on how much joints need to move
                            float max_joint_change = 0.0f;
                            for (int i = 0; i < 4; i++) {
                                float change = fabs(flipped(i) - current_q(i));
                                if (change > max_joint_change) max_joint_change = change;
                            }
                            flip_duration = fmax(0.8f, fmin(2.0f, max_joint_change / 1.5f));
                            
                            // Store final Cartesian target - Jacobian takes over after flip
                            flip_final_cartesian(0) = x;
                            flip_final_cartesian(1) = y;
                            flip_final_cartesian(2) = z;
                            flip_final_roll = roll;
                            
                            flip_mode = true;
                            cartesian_mode = false;  // Will be enabled after flip
                            center_crossing_mode = false;
                            moving = false;
                            sweep_mode = false;
                            direct_joint_mode = false;
                            
                            Serial.printf("OK FLIP MODE: Flipping arm (%.1fs) then Jacobian to (%.1f, %.1f, %.1f)\n", 
                                flip_duration, x, y, z);
                            Serial.printf("   Flip q: (%.2f,%.2f,%.2f,%.2f) -> (%.2f,%.2f,%.2f,%.2f)\n",
                                current_q(0), current_q(1), current_q(2), current_q(3),
                                flipped(0), flipped(1), flipped(2), flipped(3));
                        } else {
                            // Flipped config hits limits - fall back to regular Jacobian
                            Serial.println("WARN: Flip config hits limits, using direct Jacobian");
                            cartesian_target(0) = x;
                            cartesian_target(1) = y;
                            cartesian_target(2) = z;
                            move_target_roll = roll;
                            center_crossing_mode = false;
                            flip_mode = false;
                            cartesian_mode = true;
                            moving = false;
                            sweep_mode = false;
                            direct_joint_mode = false;
                        }
                    } else {
                        // Normal direct move - let Jacobian handle it
                        cartesian_target(0) = x;
                        cartesian_target(1) = y;
                        cartesian_target(2) = z;
                        move_target_roll = roll;
                        center_crossing_mode = false;
                        flip_mode = false;
                        cartesian_mode = true;
                        moving = false;
                        sweep_mode = false;
                        direct_joint_mode = false;
                        Serial.printf("OK Moving to (%.1f, %.1f, %.1f) roll=%.2f\n", x, y, z, roll);
                    }
                    
                    xSemaphoreGive(stateMutex);
                }
            } else {
                Serial.println("ERR: Invalid M command. Use: M x y z roll time");
            }
        } else if (cmd.startsWith("J")) { // Joint Move: J q1 q2 q3 q4 roll time
            float q1, q2, q3, q4, roll, t;
            if (sscanf(cmd.c_str(), "J %f %f %f %f %f %f", &q1, &q2, &q3, &q4, &roll, &t) == 6) {
                if (xSemaphoreTake(stateMutex, pdMS_TO_TICKS(100)) == pdTRUE) {
                    move_start_q = current_q;
                    move_end_q = {q1, q2, q3, q4};
                    move_start_roll = current_roll;
                    move_end_roll = roll;
                    move_duration_global = t;
                    moving = true;
                    joint_mode = true; // Disable IK
                    direct_joint_mode = false;
                    xSemaphoreGive(stateMutex);
                    Serial.printf("OK Joint move to (%.2f, %.2f, %.2f, %.2f, %.2f) in %.2fs\n", 
                        q1, q2, q3, q4, roll, t);
                }
            } else {
                Serial.println("ERR: Invalid J command. Use: J q1 q2 q3 q4 roll time");
            }
        } else if (cmd.startsWith("D")) { // Direct joint target: D q1 q2 q3 q4 roll
            float q1, q2, q3, q4, roll;
            if (sscanf(cmd.c_str(), "D %f %f %f %f %f", &q1, &q2, &q3, &q4, &roll) == 5) {
                if (xSemaphoreTake(stateMutex, pdMS_TO_TICKS(100)) == pdTRUE) {
                    direct_joint_target = {q1, q2, q3, q4};
                    direct_roll_target = roll;
                    direct_joint_mode = true;
                    moving = false;
                    sweep_mode = false;
                    cartesian_mode = false;
                    xSemaphoreGive(stateMutex);
                }
            }
        } else if (cmd.startsWith("PC")) { // Path Clear: PC - clear waypoint queue
            if (xSemaphoreTake(stateMutex, pdMS_TO_TICKS(100)) == pdTRUE) {
                path_count = 0;
                path_current_idx = 0;
                path_mode = false;
                path_waiting = false;
                xSemaphoreGive(stateMutex);
                Serial.println("OK Path cleared");
            }
        } else if (cmd.startsWith("PA")) { // Path Add: PA x y z roll wait - add waypoint
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

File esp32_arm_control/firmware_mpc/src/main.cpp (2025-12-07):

/**
 * Hybrid Jacobian+MPC 5DOF Arm Controller
 * 
 * REVISED ARCHITECTURE (v3):
 * - Jacobian-based Cartesian velocity control (smooth motion)
 * - Posture control in null-space (elbow-up, wrist horizontal)
 * - MPC constraint projection (safe velocities at limits)
 * - High-speed loop (500Hz+ like old firmware)
 * 
 * This combines the best of both approaches:
 * - Old firmware: Jacobian + posture control for smooth sweeps
 * - MPC: Constraint projection for safety
 * 
 * Compatible with existing arm_gui.py
 */

#include <Arduino.h>
#include <BasicLinearAlgebra.h>
#include <ArduinoJson.h>
#include <vector>

#include "ArmModel.h"
#include "TinyMPC.h"
#include "AnalyticalIK.h"
#include "JacobianController.h"
#include "ServoDriver.h"

using namespace BLA;

// ============================================================================
// Pin Definitions
// ============================================================================
#define SERVO_RX_PIN 16
#define SERVO_TX_PIN 17
#define SERVO_DIR_PIN 4

// ============================================================================
// Objects
// ============================================================================
ServoDriver servoDriver(Serial2, SERVO_DIR_PIN, SERVO_RX_PIN, SERVO_TX_PIN);
TinyMPC mpc;
JacobianController jacobian;

// ============================================================================
// Velocity Scaling for Servo Speed
// ============================================================================
// ST3215: 4096 steps/revolution, velocity in steps/s
// 1 rad/s = 4096 / (2*PI) = 652 steps/s
const float RAD_TO_STEPS = 4096.0f / (2.0f * M_PI);

// Minimum motor speed - motors jitter below this
const int MIN_MOTOR_SPEED = 50;

// ============================================================================
// State Variables
// ============================================================================
SemaphoreHandle_t stateMutex;

// Current arm state
Matrix<N_JOINTS> current_q = {0, 0, 0, 0};
Matrix<N_JOINTS> current_q_dot = {0, 0, 0, 0};
Matrix<N_JOINTS> prev_q = {0, 0, 0, 0};
float current_roll = 0;
float prev_roll = 0;

// Target state
Matrix<3> cartesian_target = {200, 0, 200};
Matrix<N_JOINTS> target_q = {0, 0, 0, 0};
float target_roll = 0;
float target_wrist_angle = 0.0f;

// Mode flags
volatile bool torque_enabled = true;
volatile bool cartesian_mode = false;
volatile bool direct_mode = false;
volatile bool sweep_mode = false;
volatile bool moving = false;

// Speed and wrist settings
float speed_multiplier = 2.0f;
bool wrist_locked = true;

// Raw positions for telemetry
int rawPositions[N_MOTORS] = {2207, 2617, 2771, 2563, 2160, 2047};
int lastPositions[N_MOTORS] = {2207, 2617, 2771, 2563, 2160, 2047};

// Read failure tracking
int readFailCount = 0;
const int MAX_READ_FAILS = 10;

// Motor IDs
std::vector<uint8_t> motor_ids = {1, 2, 3, 4, 5, 6};

// ============================================================================
// Sweep Mode Variables
// ============================================================================
int sweep_axis = 0;
float sweep_velocity = 50.0f;
int sweep_direction = 1;
Matrix<3> sweep_start_pos = {0, 0, 0};
bool sweep_initialized = false;

// ============================================================================
// Path Mode Variables
// ============================================================================
struct Waypoint {
    Matrix<3> pos;
    float roll;
    float wait_time;
};

const int MAX_WAYPOINTS = 32;
Waypoint waypoints[MAX_WAYPOINTS];
int waypoint_count = 0;
int current_waypoint = 0;
bool path_mode = false;
float path_blend_radius = 15.0f;
bool path_waiting = false;
unsigned long path_wait_start = 0;

// ============================================================================
// Backlash Compensation (from old firmware)
// ============================================================================
int prev_direction[6] = {0, 0, 0, 0, 0, 0};
float backlash_offset[6] = {0, 0, 0, 0, 0, 0};

void applyBacklashCompensation(std::vector<int>& speeds) {
    const int BACKLASH_STEPS = 7;  // ~0.6 degrees
    const int SPEED_THRESHOLD = 10;
    
    for (size_t i = 0; i < speeds.size() && i < 6; i++) {
        int new_direction = 0;
        if (speeds[i] > SPEED_THRESHOLD) new_direction = 1;
        else if (speeds[i] < -SPEED_THRESHOLD) new_direction = -1;
        
        if (new_direction != 0 && prev_direction[i] != 0 && new_direction != prev_direction[i]) {
            backlash_offset[i] = BACKLASH_STEPS * new_direction;
        }
        
        if (backlash_offset[i] != 0.0f && new_direction != 0) {
            float comp_speed = backlash_offset[i] * 50.0f;
            speeds[i] += (int)comp_speed;
            
            float decay = fabs(speeds[i]) * 0.001f;
            if (decay < 0.5f) decay = 0.5f;
            if (backlash_offset[i] > 0) {
                backlash_offset[i] -= decay;
                if (backlash_offset[i] < 0) backlash_offset[i] = 0;
            } else {
                backlash_offset[i] += decay;
                if (backlash_offset[i] > 0) backlash_offset[i] = 0;
            }
        }
        
        if (new_direction != 0) {
            prev_direction[i] = new_direction;
        }
    }
}

// ============================================================================
// Statistics
// ============================================================================
unsigned long last_control_time = 0;
float mpc_solve_time = 0;

// ============================================================================
// Helper Functions
// ============================================================================

bool readAllPositions(std::vector<int>& positions) {
    bool success = servoDriver.syncReadPosition(motor_ids, positions);
    
    if (success) {
        bool all_valid = true;
        for (size_t i = 0; i < positions.size(); i++) {
            if (positions[i] < 0 || positions[i] > 4095) {
                positions[i] = lastPositions[i];
                all_valid = false;
            } else {
                lastPositions[i] = positions[i];
            }
        }
        readFailCount = 0;
        return all_valid;
    } else {
        readFailCount++;
        for (size_t i = 0; i < positions.size(); i++) {
            positions[i] = lastPositions[i];
        }
        return false;
    }
}
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

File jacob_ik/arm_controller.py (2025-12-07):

import threading
import time
import json
import numpy as np
import kinematics
import trajectory
import joint_control
from STservo_sdk import *

class PID:
    """A simple PID controller."""
    def __init__(self, Kp, Ki, Kd, setpoint, output_limits):
        self.Kp, self.Ki, self.Kd = Kp, Ki, Kd
        self.setpoint = setpoint
        self.min_output, self.max_output = output_limits
        self.last_error, self.integral = 0, 0
        self.last_time = time.time()

    def compute(self, current_value):
        current_time = time.time()
        dt = current_time - self.last_time
        if dt <= 0: return 0
        error = self.setpoint - current_value
        self.integral += error * dt
        derivative = (error - self.last_error) / dt
        output = (self.Kp * error) + (self.Ki * self.integral) + (self.Kd * derivative)
        self.last_error = error
        self.last_time = current_time
        return np.clip(output, self.min_output, self.max_output)

class ArmController:
    def __init__(self, gui_app):
        self.gui = gui_app
        self.portHandler = None
        self.packetHandler = None
        self.groupSyncWrite = None
        self.groupSyncRead = None
        self.servo_limits = {}
        self.motor_ids = []
        self.torque_states = {}
        self.current_q_rad = np.array([0.0, np.pi/2, 0.0, 0.0])
        self.raw_motor_data = {}
        self.polling_thread = None
        self.motion_thread = None
        self.joint_follower_threads = {}
        self.stop_all_threads = threading.Event()
        self.stop_motion_flag = threading.Event()
        self.stop_joint_motion_flags = {}
        self.scanning_in_progress = False
        
        self.joint_controllers = {}
        self.trajectory_gen = trajectory.TrajectoryGenerator()
        self.lock = threading.Lock() # Lock for serial port access
        
        self._load_servo_limits()

    def _load_servo_limits(self):
        try:
            with open('jacob_ik/servo_limits.json', 'r') as f: self.servo_limits = json.load(f)
        except Exception as e:
            self.gui.update_status(f"Warning: Could not load servo_limits.json. Error: {e}")

    def _init_joint_controllers(self):
        self.joint_controllers = {}
        # Motor map: 0->1 (Base), 1->2 (Shoulder), 2->4 (Elbow), 3->5 (Wrist)
        motor_map = {0: 1, 1: 2, 2: 4, 3: 5}
        
        for i in range(4):
            mid = motor_map[i]
            sid = str(mid)
            if sid in self.servo_limits:
                params = self.servo_limits[sid]
                self.joint_controllers[i] = joint_control.JointController(
                    motor_id=mid,
                    kp=params.get('kp', 4.0),
                    ki=params.get('ki', 0.1),
                    kd=params.get('kd', 0.5),
                    max_vel=params.get('max_vel', 2.0),
                    max_accel=params.get('max_accel', 5.0)
                )
            else:
                # Defaults
                self.joint_controllers[i] = joint_control.JointController(motor_id=mid)

    def connect(self, port):
        self.scanning_in_progress = True
        self.stop_all_threads.clear()
        try:
            self.portHandler = PortHandler(port)
            self.packetHandler = sts(self.portHandler)
            if not self.portHandler.openPort() or not self.portHandler.setBaudRate(1000000):
                raise Exception("Port setup failed")
            
            # Initialize Sync Read/Write
            # STS_GOAL_SPEED_L = 46, 2 bytes
            self.groupSyncWrite = GroupSyncWrite(self.packetHandler, STS_GOAL_SPEED_L, 2)
            # STS_PRESENT_POSITION_L = 56, 2 bytes
            self.groupSyncRead = GroupSyncRead(self.packetHandler, STS_PRESENT_POSITION_L, 2)
            
        except Exception as e:
            self.gui.on_scan_complete([]); self.gui.update_status(f"Error: {e}"); return
        threading.Thread(target=self._scan_worker, daemon=True).start()

    def stop_scan(self):
        self.scanning_in_progress = False

    def _scan_worker(self):
        print("Scan worker started")
        found_motors = []
        for motor_id in range(253):
            if not self.scanning_in_progress: break
            with self.lock:
                res = self.packetHandler.ping(motor_id)
                # print(f"Ping {motor_id}: {res}")
                if res[1] == COMM_SUCCESS: 
                    print(f"Found motor {motor_id}")
                    found_motors.append(motor_id)
            time.sleep(0.001)
        self.scanning_in_progress = False
        print(f"Scan complete. Found: {found_motors}")
        self.gui.master.after(0, self.gui.on_scan_complete, found_motors)
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

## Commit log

2025-11-16 Initial commit with Git LFS for STL files
    [5909K18_Needle-Roller Thrust Bearing.SLDPRT, 5909K78_1 mm Thick Washer for 35 mm Shaft Diameter Needle-Roller Thrust Bearing.SLDPRT, 5972K216_Ball Bearing.SLDP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]
2025-11-17 Adding STservo_sdk and other env requirements.
    [pyvenv.cfg]
2025-12-07 feat: Complete Teensy 4.1 QP-MPC implementation with 815Hz control and automatic tuning
    Major additions:
    - Teensy 4.1 firmware with QP-MPC controller (815Hz, sub-mm precision)
    - ESP32 firmware variants (Jacobian + MPC hybrid)
    - Automatic MPC parameter tuner with deep optimization mode
    - Smooth path planning with spline interpolation and loop support
    - Circular buffer management for continuous motion
    - Runtime MPC weight tuning via serial commands
    - Parameter persistence with JSON save/load
    - Comprehensive README documenting all implementations (Teensy/ESP32/Python)
    Performance: 815Hz control rate, <0.5mm error, <2s settling time
    [servo_limits.json, sweep_log.csv]
2025-12-07 docs: Update servo configuration section with detailed communication protocol and SDK information
